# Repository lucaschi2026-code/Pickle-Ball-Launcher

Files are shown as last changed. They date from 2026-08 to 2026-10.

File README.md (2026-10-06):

# Pickle-Ball-Launcher
A pickleball launcher with horizontal and vertical movement, varying distance, and varying spin.

[🎥Video series🎥](https://www.youtube.com/watch?v=JF2lp_7c97A&list=PLT0-RLjuO7Rs&pp=sAgC)

[🎥Overview Video🎥](https://youtu.be/JF2lp_7c97A?si=ikQjlXj1Om9Uvilw)

## Features

- **Wi-Fi control, no app needed** — the ESP32 makes its own hotspot ("RoverControl") and serves a phone-friendly web page with a d-pad for aiming
- **Pan and tilt aiming** — two stepper motors (precise motors that move in fixed steps) swing the launcher left/right and up/down
- **Worm drive on pan (25:1)** — a worm + helical gear pair that turns slowly with lots of force and holds position when powered off
- **Segment gear on tilt (9:1)** — only the slice of gear teeth to tilt motor mount up and down
- **Two spinning launch wheels** — 775 brushed DC motors on BTS7960 H-bridges (driver boards that set speed and direction), so wheel speeds can differ to add spin
- **3D printed throughout** — including a custom roller-bearing turntable, gears, and motor mounts. All STEP files included
- **Fully documented build** — schematic (KiCad), BOM with links, firmware source, and an Improvements section listing what broke and why

# Challenges
### Short Motor Shaft

**Problem**

- Motor shafts were only 16mm in length each
- Pickleball wouldn't fit if I used a full front mount only using the screw holes in the front of the motor for mounting

**Cause**

- I bought the wrong motor :(

**Fix**

- Utilized a partial front mounts to allow space between the motors to accomadate for the pickleball
- Secured the partial front mounts to a back mount with rods for more stability
<table>
  <tr>
    <td align="center"><br><sub>Problem</sub></td>
    <td align="center"><br><sub>Solution</sub></td>
  </tr>
</table>

### Segment gear teeth not concentric with the pivot axis

[🎥Video explanation🎥](https://youtube.com/shorts/Wz2A-TTkKP4?si=VPnpqFrX6oq3ApiZ)

**Problem**

- The spur pinion could not drive the segment gear through its full travel.
- Mesh was correct at only one position in the sweep.
- Moving away from that position, the pair progressively bound up in one direction and gained backlash in the other.
- At the extremes, the teeth stopped engaging altogether.

**Cause**

- The teeth had been generated about the donor gear's center, while the part rotates about its pivot bore — two different axes.
- That offset makes the pitch circle swing rather than spin, so the pinion-to-segment center distance varies with sweep angle.

**Fix**

- Rebuilt the segment gear with its teeth and pivot on a single axis.
- Generated a complete gear centered on the pivot axis, then removed the unused material.
- All remaining teeth now lie on one pitch circle concentric with the pivot, so center distance to the pinion stays constant across the entire sweep.

https://github.com/user-attachments/assets/aec71726-0927-466b-a4a0-04b81f9691da

https://github.com/user-attachments/assets/82309e48-c833-469f-9269-4ec8329cf462

### Motor Arm Enclosure Walls Too High

[🎥Video🎥](https://youtube.com/shorts/bnbqNXNC1xM?si=NwhakDUqOzrnFfoD)

**Problem**
- Stepper motor would not seat into the motor arm enclosure
- The walls on the back side of the enclosure were too high and blocked the motor from dropping in

**Cause**
- The enclosure was modeled around NEMA 17 stepper motor, but I did not consider how I was going to get the motor in the enclosure in the first place

**Fix**
- Melted the back walls off with a soldering iron and removed them
- Fixed 3D model
- Motor drops in cleanly now — the four M3 bolts through the front wall plus the rest pads hold it securely, so the back walls turned out to be unnecessary

<table>
  <tr>
    <td align="center"><br><sub>Back View</sub></td>
    <td align="center"><br><sub>Side View</sub></td>
    <td align="center"><br><sub>Front View</sub></td>
    <td align="center"><br><sub>Solution</sub></td>
  </tr>
</table>

# What Failed?

[🎥Video Snippet🎥](https://www.youtube.com/watch?v=JF2lp_7c97A&t=4m33s)

### What happened

- At low wheel speed the ball launched just fine.
- Turning the speed up made it *worse* — the ball dribbled out of the wheels instead of flying.

### How a wheel launcher is supposed to work

- Two counter-rotating wheels squeeze the ball; friction drags it up to the **surface speed** of the wheels and it exits at about that speed.
- `surface speed = π × wheel diameter × RPM`
- This only holds if the ball doesn't **slip**. More wheel speed giving less ball speed is the signature of a traction problem, not a power problem.

### Why it failed

- **Tiny contact patch.** Scooter tread is narrow and rounded. A pickleball is a 74 mm sphere. Round pressed on round is close to a single *point*, and friction force depends on how much surface is touching. This meant every launch had to be perfectly aligned with the equator of the pickleball. Because of human error and 2 individual wheels that vibrate randomly, this was nearly impossible.

https://github.com/user-attachments/assets/05e2c2c6-3fab-460d-b990-52fe02558209

- **A pickleball won't compress easy.** A tennis ball flattens and wraps around the wheel, giving a big patch and long contact; that's why narrow wheels work in tennis machines. A pickleball is hard, hollow, and smoother. Pressing too hard with the narrow scooter wheels probably caused the pickleball to slide laterally instead of being compressed at the equator.
- **Why more speed made it worse:** a faster launch needs more force over less time. The friction *needed* goes up, the friction *available* stays the same, so more of the wheel speed is lost to slip.

### Improvements

- **Concave (grooved) wheels.** Purchase specific concave wheels so the wheel cradles the ball. Biggest single change: point contact becomes a wide wrapping patch, and the ball can't slip sideways.
- **A guide throat before and after the wheels** so the ball always enters dead centre.

### How to check whether a fix worked

- Film the launch in phone slow-motion and measure exit speed against a marked wall.
- `efficiency = ball speed ÷ wheel surface speed`
- Under ~50 % means it's still slipping badly. A good wheel launcher lands above ~80 %.

---
# Other Possible Improvements
## 1. Tilt axis wouldn't come back down

[🎥Video explanation🎥](https://www.youtube.com/shorts/tR7sy3MjvJQ)

**What happened**

- Spur gear/pinion turned the segment gear, but the mount only moved one way — tilt up and it stayed up, commanding down did nothing.
- Superglueing the lower motor to the segment gear worked briefly, then motor vibration broke the joint.

**Why**

- The segment gear was never positively fastened to the mount — only glue and friction.
- That makes a one-way drive: going up, the gear pushes the mount along. Coming down, the gear has to *pull* the mount, and the joint couldn't carry the weight of two motors in shear.
- Superglue (cyanoacrylate) is brittle — decent in a straight pull, almost no fatigue life under vibration. Two spinning motors right next to the joint is the worst case for it.

**Improvements**

- Connect the segment gear to a component on the motor mount without glue (see img below).
- Balance the assembly (move mass or add a counterweight) so the centre of gravity sits on the pivot axis. The motor then only fights friction, not weight.


---

## 2. No ball feeder

- Not a failure — it just wasn't built this time. Balls were loaded by hand.

**For a future version**

- Gravity hopper feeding a rotating disc **escapement** (a slotted wheel that lets one ball through per turn) or a servo gate.
- Optional RPM sensor so it fires when the wheels are actually ready, instead of on a fixed timer.

---

## 3. Electronics had nowhere to live

**What happened**

- The circuit ended up strapped to the outside of the frame — messy, bulky, exposed. Wiring ran wherever it could reach.

**Why**

- The enclosure and cable routing were never part of the mechanical design. Mechanics were designed first, electronics second, and by the time the boards existed no space had been reserved.



**Improvements**

- Reserve the electronics bay in CAD at the same time as the mechanics — define the box volume and mounting bosses before the frame is finalised.
- Custom PCB: the BTS7960, TMC2209 and ESP32 modules become sockets on one board. No jumper wires, far smaller, far more reliable.

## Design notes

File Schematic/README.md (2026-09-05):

Kicad schematic was used as a template for physical wiring. GND lines in Kicad are daisy chained. Physically, they are wired as a star and meet at a common point.

Kicad Schematic



GND Star



Physical Circuit



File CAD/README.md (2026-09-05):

# 3D models not made by me:
Scooter Wheels: https://grabcad.com/library/100mm-scooter-wheel-with-ball-bearings-1/details?folder_id=1247894 \
Bearings: https://grabcad.com/library/608-bearing-5

# Final Assembly
Does not include [improved segment gear](/CAD/improved_segment_gear.step)



# Note
In my real build, my back mount has 2 parts. There is a green cap that sits flush with the old back mount. I decided to combine both in Fusion.

View recent photos

Updated model



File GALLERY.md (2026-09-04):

# Gallery

## First partial assembly of the frame + temp wires


## Rat's nest


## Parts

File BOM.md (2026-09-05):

| Qty | Category | Item | Notes |
|---|---|---|---|
| 1 | Electronics | [ESP32 Dev Board](https://www.amazon.ca/ESP-WROOM-32-NodeMCU-Bluetooth-Development-Microcontroller/dp/B0CHBMFJBQ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) | WROOM-32 |
| 1 | Electronics | [ESP32 Breakout Board](https://www.amazon.ca/Create-idea-ESP-WROOM-32-Microcontroller-Development/dp/B0CWL7TK7T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) | |
| 2 | Electronics | [BTS7960 DC Motor Driver](https://www.amazon.ca/CANADUINO%C2%AE-BTS7960-H-Bridge-Motor-Driver/dp/B0CTGK9XV7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) | For the 775 motors |
| 2 | Electronics | [TMC2209 Motor Driver](https://www.amazon.ca/SazkJere-TMC2209-Stepper-StepStick-Heatsinks/dp/B0H2YG1LFF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) | V2.0 stepper drivers |
| 1 | Electronics | [5V Step-Down Converter](https://www.amazon.ca/CANADUINO-DC-DC-Converter-Output-Terminals/dp/B07B2L1CDT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) | Buck converter for logic power |
| 1 | Electronics | [Rocker Switch](https://www.amazon.ca/Grote-82-2131-Rocker-Switch/dp/B00460E3QW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) | Main power switch |
| 1 | Electronics | [20A Fuse](https://www.amazon.ca/Auto-Car-Blade-Fuses-Assortment/dp/B0BPSBJX4Y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) + [Holder](https://www.amazon.ca/Nilight-Harness-Automotive-Holder-10-Warranty/dp/B07426WCLM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)| |
| 2 | Motors | [775 DC Brushed Motor](https://www.amazon.ca/dp/B088GP44QN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) | Drive motors |
| 2 | Motors | [NEMA 17 Stepper](https://www.amazon.ca/NEMA17-Stepper-Torque-Bipolar-Printer/dp/B0B1Q4CF87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) | Pan and tilt |
| 1 | Power | [5200mAh LiPo Battery](https://www.amazon.ca/HRB-Battery-Fixed-Wing-Trex-450-Helicopter/dp/B06XKWPXNM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) | 3S 11.1V |
| 1 | Power | [LiPo Battery Charger](https://www.amazon.ca/dp/B0H4PLBZ84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) | |
| 1 | Power | [TRX Male Connector Cable](https://www.amazon.ca/DEVMO-Connectors-Slicone-Battery-Turnigy/dp/B08XLX52HL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) | Traxxas plug |
| As needed | Wiring | [14 AWG Wire](https://www.amazon.ca/Silicone-Electrical-Core-Flexible-Strands/dp/B0B9JBG1SH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) | High-current runs |
| As needed | Wiring | [Jumper Wires](https://www.amazon.ca/CANADUINO%C2%AE-Dupont-Breadboard-Jumper-Wires/dp/B09TZHGLCM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) | Logic signals |
| As needed | Wiring | [Electrical Tape](https://www.amazon.ca/NSI-WW-716-Electrical-Tape/dp/B07R5L8CS1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) or [Heat Shrink](https://www.amazon.ca/ASHINER-Heat-Shrink-Tubing-User-Friendly/dp/B08XXGNJHG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)| |
| 1 | Hardware | M8 x 50mm Hex Bolt | Partially threaded |
| 1 | Hardware | M8 Nut | |
| 6 | Hardware | M5 x 25mm Hex Bolt | |
| 4 | Hardware | M4 x 12mm Machine Screw + nuts | Slotted head |
| 2 | Hardware | M3 x 5mm Screw | |
| 2 | Mechanical | [Scooter Wheel](https://www.amazon.ca/dp/B07Y9JCW16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) | |
| 4 | Mechanical | 608 Bearing | |

<!-- Link pattern: [Item Name](https://store-url-here) -->

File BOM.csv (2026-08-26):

 | Qty | Category | Item | Notes
 | --- | --- | --- | ---
 | 1 | Electronics | [ESP32 Dev Board](https://www.amazon.ca/ESP-WROOM-32-NodeMCU-Bluetooth-Development-Microcontroller/dp/B0CHBMFJBQ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 | WROOM-32
 | 1 | Electronics | [ESP32 Breakout Board](https://www.amazon.ca/Create-idea-ESP-WROOM-32-Microcontroller-Development/dp/B0CWL7TK7T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
 | 2 | Electronics | [BTS7960 DC Motor Driver](https://www.amazon.ca/CANADUINO%C2%AE-BTS7960-H-Bridge-Motor-Driver/dp/B0CTGK9XV7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 | For the 775 motors
 | 2 | Electronics | [TMC2209 Motor Driver](https://www.amazon.ca/SazkJere-TMC2209-Stepper-StepStick-Heatsinks/dp/B0H2YG1LFF?s=industrial | V2.0 stepper drivers
 | 1 | Electronics | [5V Step-Down Converter](https://www.amazon.ca/CANADUINO-DC-DC-Converter-Output-Terminals/dp/B07B2L1CDT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 | Buck converter for logic power
 | 1 | Electronics | [Rocker Switch](https://www.amazon.ca/Grote-82-2131-Rocker-Switch/dp/B00460E3QW?mcid=e3902c3fcb7f38e5adf10008658d72a9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 | Main power switch
 | 1 | Electronics | [20A Fuse](https://www.amazon.ca/Auto-Car-Blade-Fuses-Assortment/dp/B0BPSBJX4Y?mcid=dce0a65629c934d29b2b6d854531eb2c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 + [Holder](https://www.amazon.ca/Nilight-Harness-Automotive-Holder-10-Warranty/dp/B07426WCLM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
 | 2 | Motors | [775 DC Brushed Motor](https://www.amazon.ca/CHANCS-Permanent-10000RPM-Electronic-Component/dp/B088GP44QN?gad_source=1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 | Drive motors
 | 2 | Motors | [NEMA 17 Stepper](https://www.amazon.ca/NEMA17-Stepper-Torque-Bipolar-Printer/dp/B0B1Q4CF87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 | Pan and tilt
 | 1 | Power | [5200mAh LiPo Battery](https://www.amazon.ca/HRB-Battery-Fixed-Wing-Trex-450-Helicopter/dp/B06XKWPXNM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 | 3S 11.1V
 | 1 | Power | [LiPo Battery Charger](https://www.amazon.ca/Battery-Charger-Balance-7-4-11-1V-Batteries/dp/B08HN5DZ5Y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
 | 1 | Power | [TRX Male Connector Cable](https://www.amazon.ca/DEVMO-Connectors-Slicone-Battery-Turnigy/dp/B08XLX52HL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 | Traxxas plug
 | As needed | Wiring | [14 AWG Wire](https://www.amazon.ca/Silicone-Electrical-Core-Flexible-Strands/dp/B0B9JBG1SH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 | High-current runs
 | As needed | Wiring | [Jumper Wires](https://www.amazon.ca/CANADUINO%C2%AE-Dupont-Breadboard-Jumper-Wires/dp/B09TZHGLCM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 | Logic signals
 | As needed | Wiring | [Electrical Tape](https://www.amazon.ca/NSI-WW-716-Electrical-Tape/dp/B07R5L8CS1?s=industrial or [Heat Shrink](https://www.amazon.ca/ASHINER-Heat-Shrink-Tubing-User-Friendly/dp/B08XXGNJHG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
 | 1 | Hardware | M8 x 50mm Hex Bolt | Partially threaded
 | 1 | Hardware | M8 Nut
 | 6 | Hardware | M5 x 25mm Hex Bolt
 | 4 | Hardware | M4 x 12mm Machine Screw | Slotted head
 | 2 | Mechanical | [Scooter Wheel](https://www.amazon.ca/dp/B07Y9JCW16?sp_csd=d2lkZ2V0TmFtZT1zcF9kZXRhaWw
 | 4 | Mechanical | 608 Bearing]
<!-- Link pattern: [Item Name](https://store-url-here) -->

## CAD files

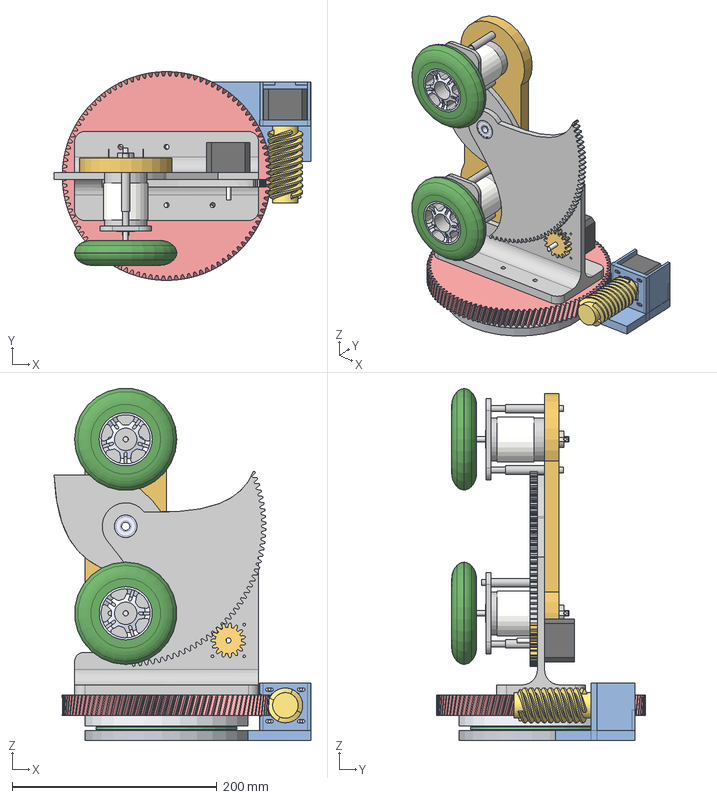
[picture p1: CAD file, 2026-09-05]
CAD/final_assembly.step
251.0 x 204.0 x 343.9 mm
bottom_ring
roller_cage
roller_01
roller_02
roller_03
roller_04
roller_05
roller_06
roller_07
roller_08
roller_09
roller_10
roller_11
roller_12
roller_13
roller_14
roller_15
roller_16
roller_17
roller_18
roller_19
roller_20
roller_21
roller_22
roller_23
roller_24
top_ring
motor_arm
worm

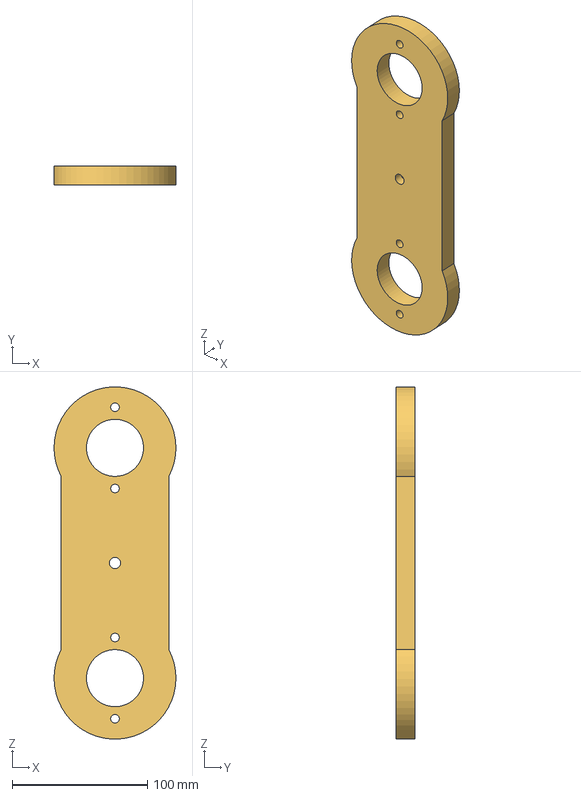
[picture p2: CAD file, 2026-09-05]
CAD/back_mount.step
90.0 x 14.0 x 259.8 mm

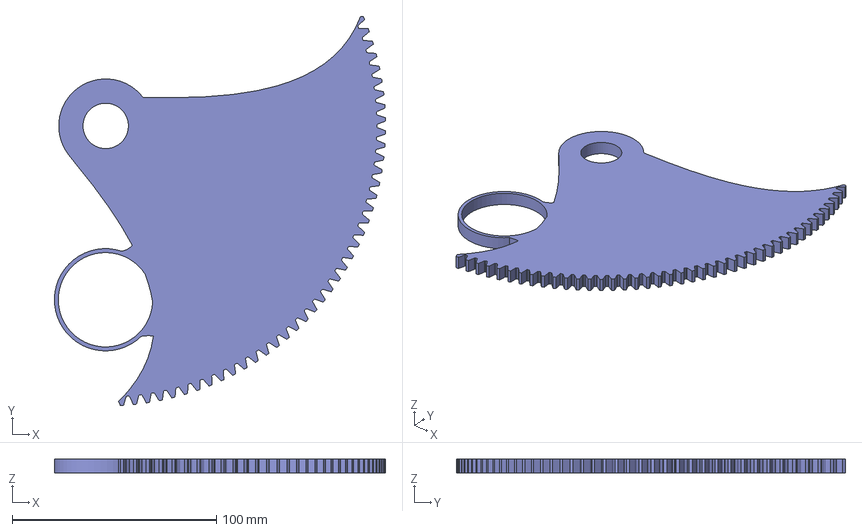
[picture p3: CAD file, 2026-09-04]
CAD/improved_segment_gear.step
162.1 x 190.4 x 7.00 mm

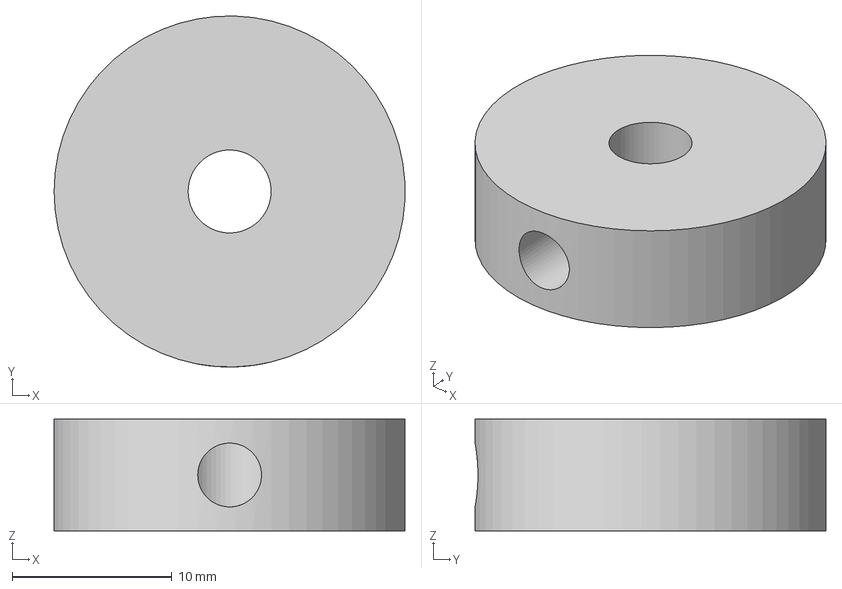
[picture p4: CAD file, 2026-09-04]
CAD/hub.step
22.0 x 22.0 x 7.00 mm

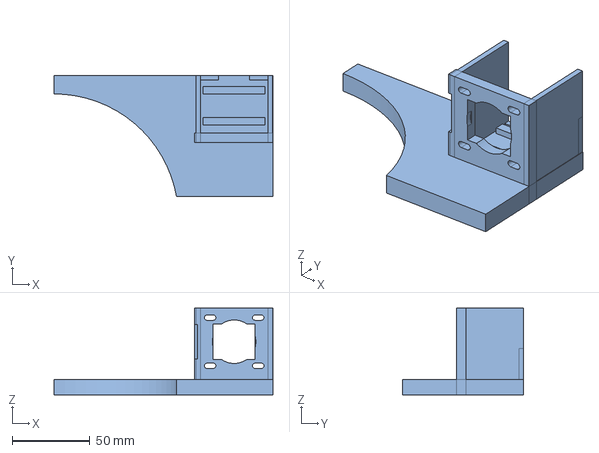
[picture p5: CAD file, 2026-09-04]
CAD/motor_arm.step
141.0 x 78.0 x 56.0 mm

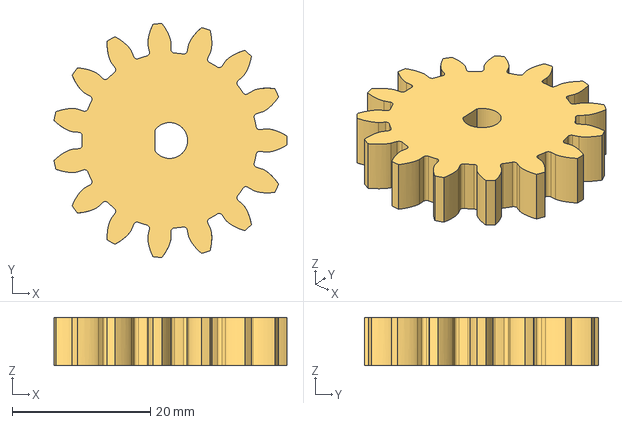
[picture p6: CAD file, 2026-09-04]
CAD/spur_gear.step
33.8 x 33.9 x 7.00 mm

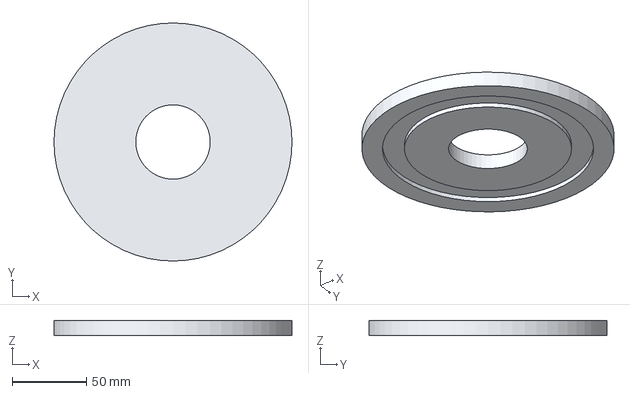
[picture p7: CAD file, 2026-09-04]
CAD/top_ring.step
160.0 x 160.0 x 10.0 mm

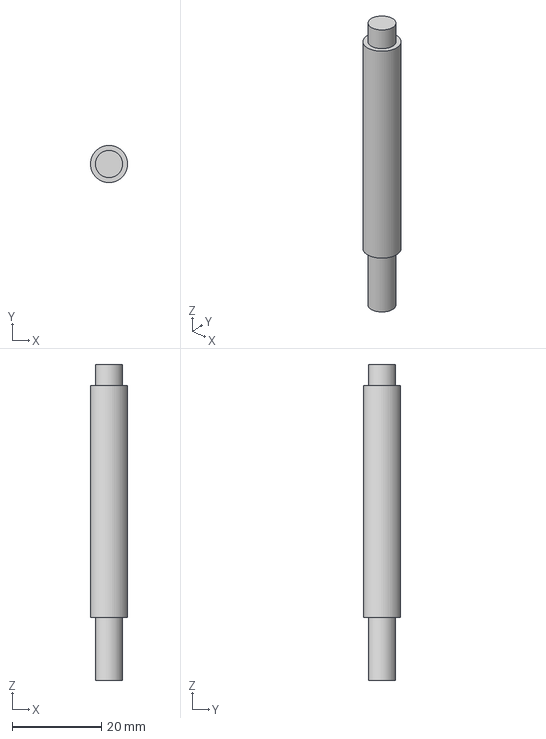
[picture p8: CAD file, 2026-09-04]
CAD/rod.step
8.34 x 8.35 x 71.0 mm

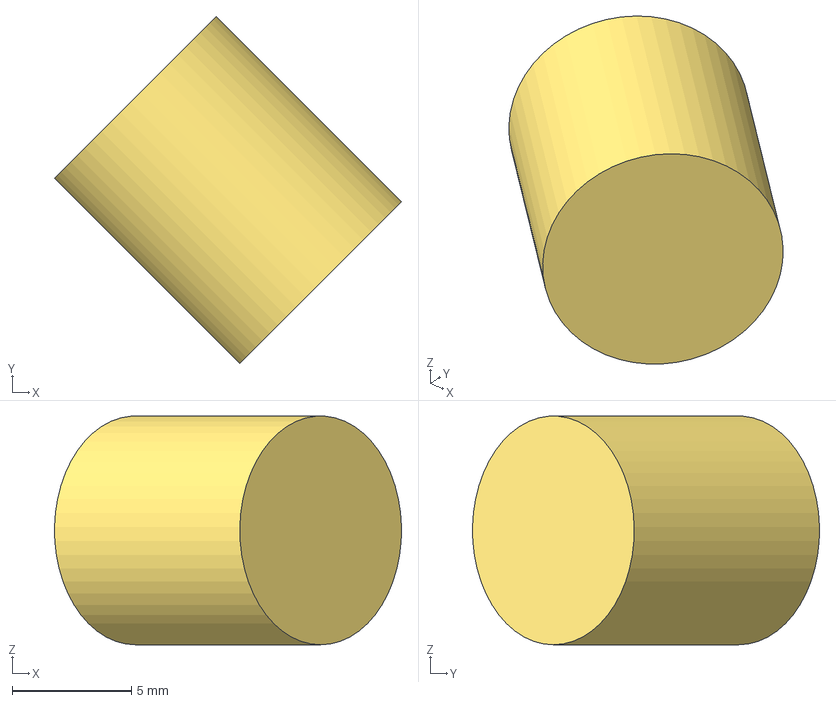
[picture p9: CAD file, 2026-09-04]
CAD/roller.step
14.6 x 14.6 x 9.59 mm

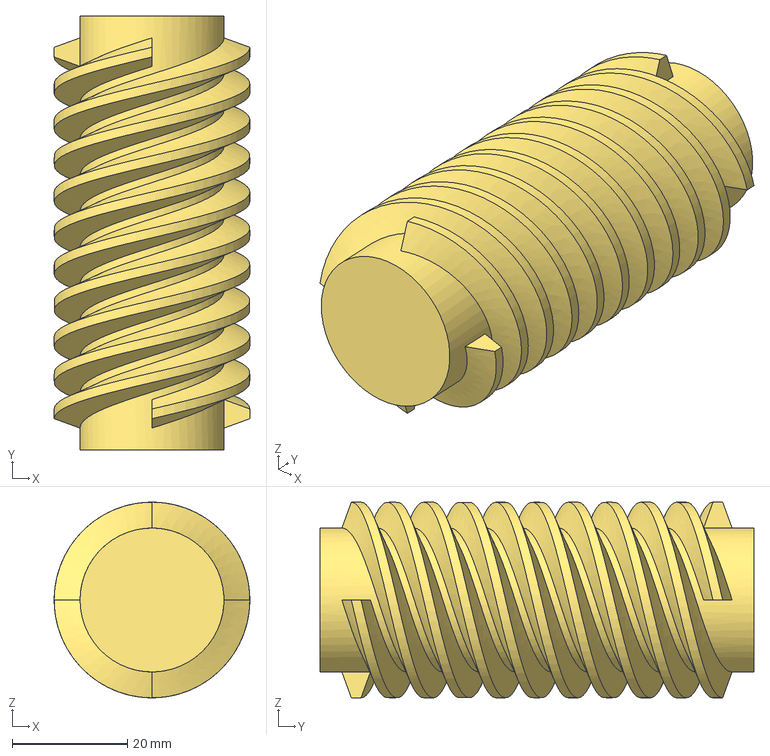
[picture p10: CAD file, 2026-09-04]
CAD/worm_gear.step
34.0 x 75.4 x 34.0 mm

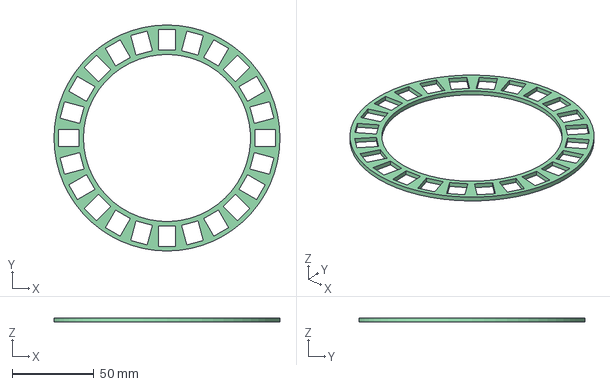
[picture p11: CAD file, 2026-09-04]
CAD/roller_cage.step
138.0 x 138.0 x 2.50 mm

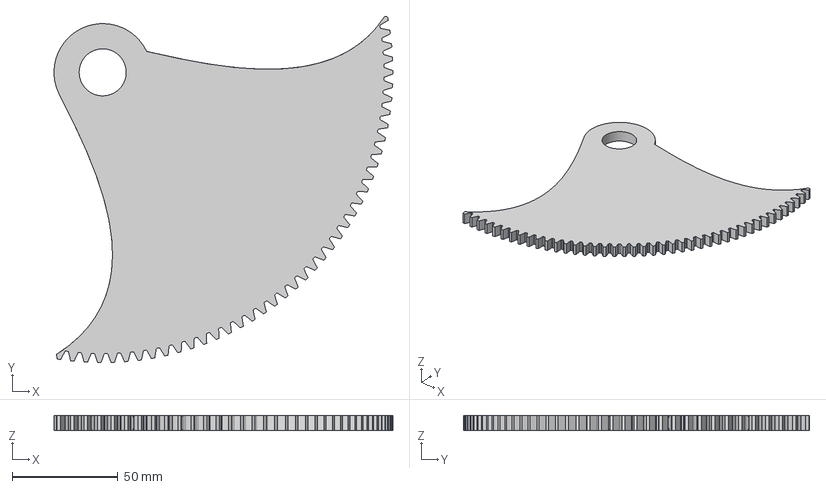
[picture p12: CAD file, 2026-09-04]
CAD/segment_gear.step
160.0 x 163.4 x 7.00 mm

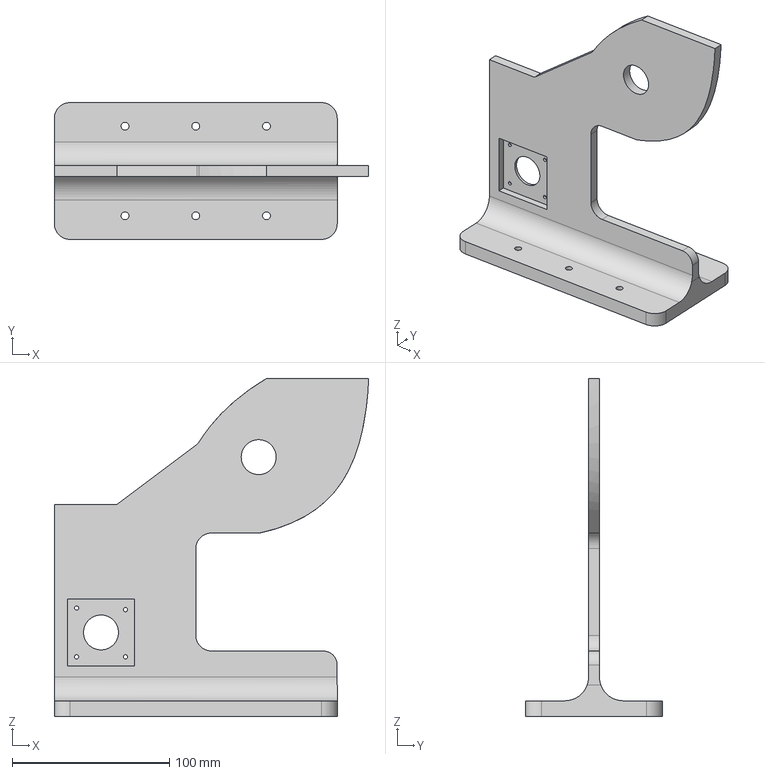
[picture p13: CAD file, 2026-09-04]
CAD/vert_mount.step
200.0 x 87.0 x 215.0 mm

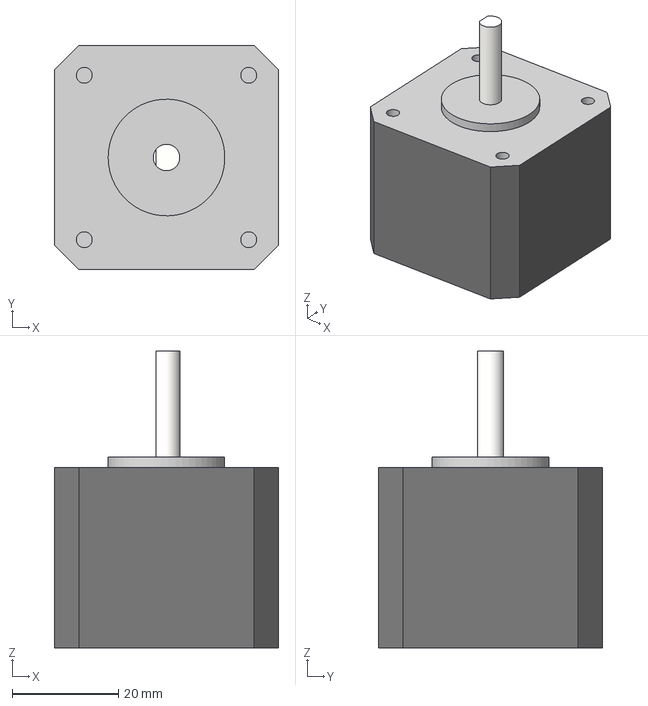
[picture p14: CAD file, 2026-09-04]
CAD/stepper.step
42.3 x 42.3 x 56.0 mm

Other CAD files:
CAD/bottom_ring.step
CAD/bplate.step
CAD/motor.step
CAD/screw_mount.step

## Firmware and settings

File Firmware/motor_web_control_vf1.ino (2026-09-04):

/*
 * ESP32 web control -- two BTS7960 drive motors + two TMC2209 steppers
 * --------------------------------------------------------------------
 * Board:  ESP32 Dev Module (WROOM-32)
 * Core:   arduino-esp32 v3.x   (v2.x alternatives noted at each API call)
 *
 * Connect phone to WiFi "RoverControl", password "rover1234",
 * then open  http://192.168.4.1
 *
 * DRIVE MOTORS -- forward only.
 *   The two motors face opposite ways, so they run on opposite half-bridges:
 *   motor 1 on RPWM, motor 2 on LPWM. Each motor's other pin is held at 0,
 *   so no input can command reverse.
 *
 * STEPPERS -- hold-to-move jog control.
 *   Stepper 1 = TILT   (3.33:1 spur reduction, deliberately slow)
 *   Stepper 2 = PAN    (400:1 worm, self-locking, needs a high motor rate
 *                       to produce any useful platform speed)
 *   Step pulses come from a 20 kHz hardware timer interrupt, NOT from loop().
 *   That matters: loop() also runs the web server, which stalls for tens of
 *   milliseconds at a time. Generating steps there would give visibly jerky
 *   motion and skipped steps.
 *
 * SAFETY
 *  - Everything DISARMED at boot. You must press Arm.
 *  - If the phone stops sending updates for 1.5 s, everything stops.
 *  - TMC2209 EN is ACTIVE LOW (opposite to the BTS7960s). Fit a 10k pull-up
 *    from D21 to 3.3V so the steppers stay disabled while the ESP32 boots.
 *  - Not a substitute for the physical switch or the fuses.
 */

#include <WiFi.h>
#include <WebServer.h>
#include "soc/gpio_reg.h"   // GPIO_OUT_W1TS_REG / W1TC_REG for fast step pulses

// ==================== pins ====================
// drive motors
const int M1_RPWM = 26;
const int M1_LPWM = 27;
const int M2_RPWM = 32;
const int M2_LPWM = 33;
const int EN_PIN  = 13;   // both BTS7960 R_EN + L_EN, ACTIVE HIGH

// steppers
// Tilt is on D25/D14 rather than D18/D19: D18 was proven dead on this board
// (same wire and same driver worked immediately on D25). D19 was never
// shown to be faulty -- a dead DIR pin still produces motion -- but it is
// left unused since D18 sits next to it and the cause is unknown.
//
// Note: D14 glitches briefly at boot on the ESP32. Harmless here, because
// it carries DIR (direction only) and TMC_EN holds the drivers disabled
// until setup() runs. Do not put STEP on it.
const int TILT_STEP = 25;
const int TILT_DIR  = 14;
const int PAN_STEP  = 22;
const int PAN_DIR   = 23;
const int TMC_EN    = 21;   // both TMC2209 EN, ACTIVE LOW

// Which half-bridge each drive motor uses. Motor 2 is mirrored.
// Swap a motor's pair here if it turns the wrong way.
const int M1_DRIVE = M1_RPWM;
const int M1_IDLE  = M1_LPWM;
const int M2_DRIVE = M2_LPWM;
const int M2_IDLE  = M2_RPWM;

// ==================== tuning ====================
const int PWM_FREQ = 10000;   // 10 kHz
const int PWM_BITS = 8;       // 0-255

/*  Stepper speeds, in motor microsteps per second.
 *  Assumes 1/8 microstepping: 200 full steps x 8 = 1600 microsteps per
 *  motor revolution.
 *
 *  TILT -- 3.33:1
 *    1600 x 3.33 = 5328 microsteps per degree-of-arc revolution
 *    400 steps/s  ->  0.25 motor rev/s  ->  about 27 deg/s at the arm
 *
 *  PAN -- 400:1 worm
 *    1600 x 400 = 640,000 microsteps per platform revolution
 *    8000 steps/s -> 5 motor rev/s (300 rpm) -> about 4.5 deg/s at the platform
 *
 *  The huge difference is entirely the gearing. Pan needs a fast motor to
 *  move the platform at all; tilt needs a slow one to stay controllable.
 *
 *  If pan stalls or screeches, lower PAN_MAX_SPS. A NEMA 17 on 11.1V starts
 *  losing torque badly somewhere around 300-400 rpm.
 */
const int32_t TILT_MAX_SPS = 400;
const int32_t PAN_MAX_SPS  = 8000;

// Acceleration, steps/s^2. Steppers cannot start at full speed from rest --
// without a ramp the motor just buzzes and skips.
const int32_t TILT_ACCEL = 1500;    // reaches full speed in ~0.27 s
const int32_t PAN_ACCEL  = 16000;   // reaches full speed in ~0.50 s

// Set true if an axis jogs the wrong way. Easier than resoldering.
const bool TILT_INVERT = false;
const bool PAN_INVERT  = true;    // left/right were reversed on this build

// ==================== network ====================
const char* AP_SSID = "RoverControl";
const char* AP_PASS = "rover1234";   // min 8 chars

WebServer server(80);

// ==================== state ====================
int  speed1 = 0;              // 0..255, forward only
int  speed2 = 0;
bool armed  = false;
unsigned long lastCommand = 0;
unsigned long lastRamp    = 0;
const unsigned long TIMEOUT_MS = 1500;

// ==================== stepper engine ====================
/*  Direct digital synthesis: a fixed-rate timer adds `inc` to an accumulator
 *  every tick. Each time the accumulator crosses 65536 it emits one step
 *  pulse and subtracts 65536. Changing `inc` changes the step rate smoothly,
 *  with no timer reconfiguration and no drift.
 */
const uint32_t TICK_HZ = 20000;          // ISR rate -> 20,000 steps/s ceiling

struct Axis {
  uint8_t  stepPin;
  uint8_t  dirPin;
  bool     invert;
  int32_t  maxRate;              // steps/s
  int32_t  accel;                // steps/s^2
  volatile uint32_t acc;         // DDS accumulator
  volatile uint32_t inc;         // DDS increment (written by loop, read by ISR)
  int32_t  rate;                 // current rate magnitude, steps/s
  int8_t   cmdDir;               // -1, 0, +1 requested by the UI
  int8_t   curDir;               // -1 or +1 currently set on the DIR pin
};

Axis axTilt = { TILT_STEP, TILT_DIR, TILT_INVERT, TILT_MAX_SPS, TILT_ACCEL, 0, 0, 0, 0, 1 };
Axis axPan  = { PAN_STEP,  PAN_DIR,  PAN_INVERT,  PAN_MAX_SPS,  PAN_ACCEL,  0, 0, 0, 0, 1 };

hw_timer_t* stepTimer = nullptr;

// All STEP pins, as a register bit mask.
static const uint32_t STEP_MASK = (1UL << TILT_STEP) | (1UL << PAN_STEP);

/*  Pulse generation.
 *  A STEP pulse is started on the tick that fires it and cleared at the top
 *  of the NEXT tick, giving a 50 us high time. The TMC2209 needs a minimum
 *  of 100 ns; trying to hit that with a handful of NOPs is unreliable --
 *  the exact width depends on CPU clock and compiler output, and a marginal
 *  pulse may latch on one driver and not on another. Spanning a whole tick
 *  removes the timing question entirely and costs nothing.
 */
void IRAM_ATTR onStepTimer() {
  REG_WRITE(GPIO_OUT_W1TC_REG, STEP_MASK);   // end previous tick's pulse

  uint32_t fire = 0;

  uint32_t i = axTilt.inc;
  if (i) {
    axTilt.acc += i;
    if (axTilt.acc >= 65536UL) { axTilt.acc -= 65536UL; fire |= (1UL << TILT_STEP); }
  }

  i = axPan.inc;
  if (i) {
    axPan.acc += i;
    if (axPan.acc >= 65536UL) { axPan.acc -= 65536UL; fire |= (1UL << PAN_STEP); }
  }

  if (fire) REG_WRITE(GPIO_OUT_W1TS_REG, fire);
}

// Called from loop() every few ms. Ramps rate toward target and, when the
// axis has come to a full stop, applies any pending direction change.
void rampAxis(Axis &a, uint32_t dtMs) {
  int32_t target = (a.cmdDir == 0) ? 0 : a.maxRate;

  // Never reverse while moving -- decelerate to zero first.
  if (a.cmdDir != 0 && a.cmdDir != a.curDir) target = 0;

  int32_t delta = (int32_t)(((int64_t)a.accel * dtMs) / 1000);
  if (delta < 1) delta = 1;

  if      (a.rate < target) { a.rate += delta; if (a.rate > target) a.rate = target; }
  else if (a.rate > target) { a.rate -= delta; if (a.rate < target) a.rate = target; }

  if (a.rate == 0 && a.cmdDir != 0 && a.cmdDir != a.curDir) {
    a.curDir = a.cmdDir;
    Serial.print("DIR pin ");
    Serial.print(a.dirPin);
    Serial.print(" -> ");
    Serial.println((int)a.curDir);
  }

  /*  DIR is written on EVERY pass, not just when it changes. If a single
   *  write were ever missed -- bad solder joint, brownout, glitch -- then
   *  curDir and the physical pin would disagree permanently, and both jog
   *  directions would drive the motor the same way with no way to recover.
   *  curDir only changes while stopped, so rewriting mid-move is harmless.
   */
  bool level = (a.curDir > 0);
  if (a.invert) level = !level;
  digitalWrite(a.dirPin, level ? HIGH : LOW);

  a.inc = (uint32_t)(((uint64_t)a.rate << 16) / TICK_HZ);
}

void stopSteppers() {
  axTilt.cmdDir = 0; axTilt.rate = 0; axTilt.inc = 0; axTilt.acc = 0;
  axPan.cmdDir  = 0; axPan.rate  = 0; axPan.inc  = 0; axPan.acc  = 0;
}

// ==================== drive motors ====================
void driveMotor(int drivePin, int idlePin, int value) {
  value = constrain(value, 0, 255);   // negatives clipped -- no reverse
  if (!armed) value = 0;
  ledcWrite(idlePin, 0);
  ledcWrite(drivePin, value);
}

void applySpeeds() {
  driveMotor(M1_DRIVE, M1_IDLE, speed1);
  driveMotor(M2_DRIVE, M2_IDLE, speed2);
}

void stopAll() {
  speed1 = 0;
  speed2 = 0;
  applySpeeds();
  stopSteppers();
}

void disarm() {
  armed = false;
  stopAll();
  digitalWrite(EN_PIN, LOW);    // BTS7960 off  (active high)
  digitalWrite(TMC_EN, HIGH);   // TMC2209 off  (active LOW)
}

// ==================== web page ====================
const char PAGE_HTML[] PROGMEM = R"HTML(
<!DOCTYPE html><html><head>
<meta charset="utf-8">
<meta name="viewport" content="width=device-width,initial-scale=1,user-scalable=no">
<title>Rover</title>
<style>
  :root{
    --bg:#12151a; --panel:#1b2029; --line:#2c333f;
    --text:#e8ecf2; --dim:#8b95a5;
    --live:#4fd18b; --idle:#8b95a5; --stop:#e5484d;
  }
  *{box-sizing:border-box;-webkit-tap-highlight-color:transparent}
  body{margin:0;padding:18px;background:var(--bg);color:var(--text);
       font:16px/1.4 ui-monospace,SFMono-Regular,Menlo,monospace}
  h1{font-size:13px;letter-spacing:.18em;text-transform:uppercase;
     color:var(--dim);font-weight:500;margin:0 0 18px}
  .status{display:flex;align-items:center;gap:9px;margin-bottom:20px;font-size:14px}
  .dot{width:9px;height:9px;border-radius:50%;background:var(--idle)}
  .dot.on{background:var(--live);box-shadow:0 0 10px var(--live)}
  .card{background:var(--panel);border:1px solid var(--line);
        border-radius:10px;padding:16px;margin-bottom:12px}
  .row{display:flex;justify-content:space-between;align-items:baseline;margin-bottom:12px}
  .name{font-size:13px;letter-spacing:.1em;text-transform:uppercase;color:var(--dim)}
  .val{font-size:26px;font-variant-numeric:tabular-nums}
  .sub{font-size:12px;color:var(--dim);margin-top:10px;text-align:center}
  input[type=range]{width:100%;height:38px;margin:0;background:transparent;
                    -webkit-appearance:none;appearance:none}
  input[type=range]::-webkit-slider-runnable-track{height:5px;border-radius:3px;background:var(--line)}
  input[type=range]::-webkit-slider-thumb{-webkit-appearance:none;width:34px;height:34px;
    border-radius:50%;background:var(--text);margin-top:-15px;border:none}
  input[type=range]::-moz-range-track{height:5px;border-radius:3px;background:var(--line)}
  input[type=range]::-moz-range-thumb{width:34px;height:34px;border-radius:50%;
    background:var(--text);border:none}
  .ticks{display:flex;justify-content:space-between;font-size:11px;color:var(--dim);margin-top:2px}
  button{width:100%;padding:16px;font:inherit;font-size:14px;letter-spacing:.12em;
         text-transform:uppercase;border-radius:10px;border:1px solid var(--line);
         background:var(--panel);color:var(--text);margin-bottom:10px}
  button:active{transform:translateY(1px)}
  #arm.on{background:var(--live);border-color:var(--live);color:#0d1117}
  #stop{background:var(--stop);border-color:var(--stop);color:#fff;
        padding:24px;font-size:17px;margin-top:6px}
  .link{display:flex;align-items:center;gap:11px;font-size:14px;color:var(--dim);
        padding:14px 2px}
  .link input{width:22px;height:22px;accent-color:var(--live)}
  .pad{display:grid;gap:8px;touch-action:none;
       grid-template-columns:repeat(3,1fr);
       grid-template-areas:". u ." "l c r" ". d .";}
  .pad button{margin:0;height:62px;font-size:19px;padding:0}
  .pad .u{grid-area:u} .pad .d{grid-area:d}
  .pad .l{grid-area:l} .pad .r{grid-area:r}
  .pad .c{grid-area:c;display:flex;align-items:center;justify-content:center;
          font-size:11px;color:var(--dim);letter-spacing:.1em}
  .jog.act{background:var(--live);border-color:var(--live);color:#0d1117}
  @media (prefers-reduced-motion:reduce){*{transition:none!important}}
</style></head><body>

<h1>Rover Drive</h1>
<div class="status"><div class="dot" id="dot"></div><span id="state">Disarmed</span></div>

<div class="card">
  <div class="row"><span class="name">Motor 1</span><span class="val" id="v1">0</span></div>
  <input type="range" id="s1" min="0" max="255" value="0">
  <div class="ticks"><span>Stop</span><span>Full</span></div>
</div>

<div class="card">
  <div class="row"><span class="name">Motor 2</span><span class="val" id="v2">0</span></div>
  <input type="range" id="s2" min="0" max="255" value="0">
  <div class="ticks"><span>Stop</span><span>Full</span></div>
</div>

<label class="link"><input type="checkbox" id="lk"> Link motors together</label>

<div class="card">
  <div class="row"><span class="name">Aim</span><span class="val" id="aim">--</span></div>
  <div class="pad">
    <button class="jog u" data-ax="t" data-d="1">&#9650;</button>
    <button class="jog l" data-ax="p" data-d="-1">&#9664;</button>
    <div class="c">HOLD</div>
    <button class="jog r" data-ax="p" data-d="1">&#9654;</button>
    <button class="jog d" data-ax="t" data-d="-1">&#9660;</button>
  </div>
  <div class="sub">Up / down tilts &middot; left / right pans</div>
</div>

<button id="arm">Arm motors</button>
<button id="stop">Stop</button>

<script>
const $=id=>document.getElementById(id);
let armed=false, busy=false, pending=false;
let jt=0, jp=0;                       // jog: tilt, pan  (-1 / 0 / +1)

function show(){
  $('v1').textContent=$('s1').value;
  $('v2').textContent=$('s2').value;
  $('dot').className='dot'+(armed?' on':'');
  $('state').textContent=armed?'Armed':'Disarmed';
  $('arm').textContent=armed?'Disarm motors':'Arm motors';
  $('arm').className=armed?'on':'';
  const t=jt>0?'Up':jt<0?'Down':'', p=jp>0?'Right':jp<0?'Left':'';
  $('aim').textContent=(t||p)?[t,p].filter(Boolean).join(' + '):'--';
}

async function send(){
  if(busy){ pending=true; return; }   // never drop the newest state
  busy=true;
  try{
    const q=`/set?m1=${$('s1').value}&m2=${$('s2').value}`
           +`&arm=${armed?1:0}&t=${jt}&p=${jp}`;
    const r=await fetch(q);
    const d=await r.json();
    armed=d.armed;
    if(!armed){ $('s1').value=0; $('s2').value=0; jt=0; jp=0; clearJog(); }
    show();
  }catch(e){ /* keep trying; the ESP32 watchdog stops everything */ }
  busy=false;
  if(pending){ pending=false; send(); }
}

function clearJog(){
  document.querySelectorAll('.jog').forEach(b=>b.classList.remove('act'));
}

document.querySelectorAll('.jog').forEach(btn=>{
  const ax=btn.dataset.ax, d=parseInt(btn.dataset.d,10);
  const press=e=>{ e.preventDefault();
    if(ax==='t') jt=d; else jp=d;
    btn.classList.add('act'); show(); send(); };
  const release=e=>{ e.preventDefault();
    if(ax==='t') jt=0; else jp=0;
    btn.classList.remove('act'); show(); send(); };
  btn.addEventListener('pointerdown',press);
  btn.addEventListener('pointerup',release);
  btn.addEventListener('pointercancel',release);
  btn.addEventListener('pointerleave',release);
  btn.addEventListener('contextmenu',e=>e.preventDefault());
});

function slid(e){
  if($('lk').checked){
    const v=e.target.value;
    $('s1').value=v; $('s2').value=v;
  }
  show(); send();
}
$('s1').addEventListener('input',slid);
$('s2').addEventListener('input',slid);

$('lk').addEventListener('change',()=>{
  if($('lk').checked){ $('s2').value=$('s1').value; show(); send(); }
});

$('arm').addEventListener('click',()=>{
  armed=!armed;
  if(!armed){ $('s1').value=0; $('s2').value=0; jt=0; jp=0; clearJog(); }
  show(); send();
});

$('stop').addEventListener('click',()=>{
  armed=false;
  $('s1').value=0; $('s2').value=0; jt=0; jp=0; clearJog();
  show(); send();
});

// releasing a finger outside the button still has to stop the axis
window.addEventListener('blur',()=>{ jt=0; jp=0; clearJog(); show(); send(); });

setInterval(send,400);   // heartbeat: keeps the ESP32 watchdog fed
show();
</script></body></html>
)HTML";

// ==================== handlers ====================
void handleRoot() {
  server.send_P(200, "text/html", PAGE_HTML);
}

void handleSet() {
  if (server.hasArg("arm")) {
    bool want = server.arg("arm").toInt() == 1;
    if (want != armed) {
      armed = want;
      digitalWrite(EN_PIN,  armed ? HIGH : LOW);    // BTS7960: active high
      digitalWrite(TMC_EN,  armed ? LOW  : HIGH);   // TMC2209: active LOW
      if (!armed) stopAll();
    }
  }

  // constrain() means a hand-typed URL cannot command reverse either
  if (server.hasArg("m1")) speed1 = constrain(server.arg("m1").toInt(), 0, 255);
  if (server.hasArg("m2")) speed2 = constrain(server.arg("m2").toInt(), 0, 255);

  if (server.hasArg("t")) axTilt.cmdDir = constrain(server.arg("t").toInt(), -1, 1);
  if (server.hasArg("p")) axPan.cmdDir  = constrain(server.arg("p").toInt(), -1, 1);
  if (!armed) { axTilt.cmdDir = 0; axPan.cmdDir = 0; }

  applySpeeds();
  lastCommand = millis();

  String json = "{\"armed\":";
  json += armed ? "true" : "false";
  json += ",\"m1\":" + String(speed1);
  json += ",\"m2\":" + String(speed2);
  json += ",\"tilt\":" + String(axTilt.rate);
  json += ",\"pan\":"  + String(axPan.rate) + "}";
  server.send(200, "application/json", json);
}

// ==================== setup ====================
void setup() {
  Serial.begin(115200);

  // safe state FIRST, before anything can move
  pinMode(EN_PIN, OUTPUT);
  digitalWrite(EN_PIN, LOW);          // BTS7960 disabled
  pinMode(TMC_EN, OUTPUT);
  digitalWrite(TMC_EN, HIGH);         // TMC2209 disabled (active LOW)

  pinMode(TILT_STEP, OUTPUT); digitalWrite(TILT_STEP, LOW);
  pinMode(PAN_STEP,  OUTPUT); digitalWrite(PAN_STEP,  LOW);

  // DIR must match each axis's initial curDir (+1), or the first move in the
  // + direction goes the wrong way: the code thinks no DIR write is needed.
  pinMode(TILT_DIR, OUTPUT); digitalWrite(TILT_DIR, TILT_INVERT ? LOW : HIGH);
  pinMode(PAN_DIR,  OUTPUT); digitalWrite(PAN_DIR,  PAN_INVERT  ? LOW : HIGH);

  // ---- drive PWM ---- (arduino-esp32 v3.x)
  ledcAttach(M1_RPWM, PWM_FREQ, PWM_BITS);
  ledcAttach(M1_LPWM, PWM_FREQ, PWM_BITS);
  ledcAttach(M2_RPWM, PWM_FREQ, PWM_BITS);
  ledcAttach(M2_LPWM, PWM_FREQ, PWM_BITS);
  //
  // v2.x instead:
  //   ledcSetup(0, PWM_FREQ, PWM_BITS); ledcAttachPin(M1_RPWM, 0);
  //   ledcSetup(1, PWM_FREQ, PWM_BITS); ledcAttachPin(M1_LPWM, 1);
  //   ledcSetup(2, PWM_FREQ, PWM_BITS); ledcAttachPin(M2_RPWM, 2);
  //   ledcSetup(3, PWM_FREQ, PWM_BITS); ledcAttachPin(M2_LPWM, 3);
  //   ...and change ledcWrite(pin, v) to ledcWrite(channel, v) in driveMotor().

  // ---- step timer ---- (arduino-esp32 v3.x)
  stepTimer = timerBegin(1000000);                       // 1 MHz time base
  timerAttachInterrupt(stepTimer, &onStepTimer);
  timerAlarm(stepTimer, 1000000 / TICK_HZ, true, 0);     // every 50 us
  //
  // v2.x instead:
  //   stepTimer = timerBegin(0, 80, true);              // 80 MHz / 80 = 1 MHz
  //   timerAttachInterrupt(stepTimer, &onStepTimer, true);
  //   timerAlarmWrite(stepTimer, 1000000 / TICK_HZ, true);
  //   timerAlarmEnable(stepTimer);

  stopAll();

  WiFi.softAP(AP_SSID, AP_PASS);
  Serial.print("AP up. Connect to \"");
  Serial.print(AP_SSID);
  Serial.print("\" then browse to http://");
  Serial.println(WiFi.softAPIP());

  server.on("/", handleRoot);
  server.on("/set", handleSet);
  server.begin();

  lastRamp = millis();
}

// ==================== loop ====================
void loop() {
  server.handleClient();

  // ramp stepper speeds -- every 5 ms is smooth enough and cheap
  unsigned long now = millis();
  if (now - lastRamp >= 5) {
    uint32_t dt = now - lastRamp;
    if (dt > 100) dt = 100;          // web server stalled; don't jump the ramp
    lastRamp = now;
    rampAxis(axTilt, dt);
    rampAxis(axPan,  dt);
  }

  // watchdog: no contact from the phone -> stop
  if (armed && now - lastCommand > TIMEOUT_MS) {
    Serial.println("Timeout - disarming");
    disarm();
  }
}

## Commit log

2026-06-27 Document wheel bore issues and next steps
    Added details about wheel bore diameter and design challenges.
2026-07-05 Add product link to BOM.csv
    [BOM.csv]
2026-07-27 Replace local image with hosted image link
    Updated image reference for back mount in README.
2026-08-02 Update README with challenges and solutions
    Added details about challenges faced with motor shafts and gear alignment, including the fix implemented for the segment gear.
2026-08-02 Update README with problem description for gear issue
2026-08-26 Update ESP32 Dev Board link in BOM.csv
    Replaced hyperlink formula with a direct URL for the ESP32 Dev Board.
    [BOM.csv]
2026-08-26 Remove header comment from BOM.csv
    Removed header comment from BOM.csv
    [BOM.csv]
2026-08-26 Update LiPo Battery Charger link in BOM.md
2026-08-26 Correct 608 Bearing entry in BOM.md
    Fixed formatting issue with 608 Bearing entry.
2026-09-04 Update final assembly image in README
    Replaced old image link with a new image for final assembly.
2026-09-04 Update README with improved segment gear link
2026-09-04 Update link to improved segment gear in README
2026-09-04 Add image to README for final assembly section
2026-09-05 Revise README for wheel launcher failure analysis
    Updated the README to clarify issues with the wheel launcher and proposed improvements.
2026-09-05 Update README with additional images
    Added new images to the README for star connection and physical circuit.
2026-09-05 Update README with additional schematic images
    Added images for star connection and physical circuit.
2026-09-05 Increase image sizes in README.md
    Updated image sizes for star connection and physical circuit sections.
2026-09-05 Update images in Schematic README
    Updated images in the README to provide better clarity on the GND star and physical circuit.
2026-09-05 Update README with schematic wiring explanation
2026-09-05 Modify BOM for hardware and mechanical components
    Updated BOM to include nuts for M4 screws and added M3 screws.
